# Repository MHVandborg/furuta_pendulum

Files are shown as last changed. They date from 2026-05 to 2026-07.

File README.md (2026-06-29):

# Furuta Pendulum

A Furuta (rotary inverted) pendulum system controlled by a neural network running on a custom PCB.

The system consists of a horizontal rotating arm driven by a BLDC motor, with a freely swinging pendulum attached at the end. The neural network controller learns to swing up and balance the pendulum using reinforcement learning trained in a physics simulation, then deployed directly onto the MCU.

## End Goal — Double Furuta Pendulum

The ultimate goal is a **double Furuta pendulum**: motorised arm → first free pendulum → second free pendulum, all balanced simultaneously in the inverted position by a single neural network. The current hardware (PCB rev1) targets the single pendulum first as a validated stepping stone. Double Furuta requires a PCB rev2 with a third encoder.

---

## Control Architecture

### Single Furuta (PCB rev1 — current)

```
[AS5600 arm]  [AS5600 pendulum 1]
      |               |
      +-------+-------+
              |
        [Neural Network]  MLP 2×64, trained with PPO
        inputs:  θ_arm, θ_p1, ω_arm, ω_p1
        output:  torque_command (−1…+1)
              |
        [SimpleFOC / DRV8313]
              |
        [GBM2804H-100T BLDC]
```

### Double Furuta (PCB rev2 — future)

```
[AS5600 arm]  [AS5600 pendulum 1]  [AS5600 pendulum 2]
      |               |                    |
      +-----------+---+--------------------+
                  |
            [Neural Network]  MLP 2×64 (extended inputs), trained with SAC
            inputs:  θ_arm, θ_p1, θ_p2, ω_arm, ω_p1, ω_p2
            output:  torque_command (−1…+1)
                  |
            [SimpleFOC / DRV8313]
                  |
            [GBM2804H-100T BLDC]
```

A single NN handles both swing-up and balancing via curriculum learning — it trains near vertical first, then faces progressively larger starting angles.

---

## Repository Structure

```
furuta_pendulum/
├── firmware/          # Bare-metal C (ARM GCC, CMake) → firmware/README.md
├── hardware/
│   ├── pcb/           # KiCad schematic + layout → hardware/pcb/COMPONENTS.md
│   └── mechanical/    # Fusion 360 3D design files
├── neural_network/    # RL training + Gymnasium env + exported weights → neural_network/README.md
├── bootloader/        # UF2 bootloader binary for ATSAMD51J20A
└── docs/              # Datasheets and reference documents
```

---

## Toolchain

| Area | Tools |
|---|---|
| Firmware | ARM GCC, CMake, VS Code, Atmel-ICE + Tag-Connect TC2030 (SWD), UF2 bootloader |
| ML / Training | Python, TensorFlow / Keras, Gymnasium, PPO → SAC |
| Inference on MCU | TensorFlow Lite Micro (TFLM) |
| Mechanical | Fusion 360, PLA (FDM) |
| PCB | KiCad |

---

## PCB Revision History

| Rev | Tag | Date | Notes |
|-----|-----|---|---|
| 1 | [`hw-rev1`](../../releases/tag/hw-rev1) | 2026-06-07 | First production run — JLCPCB. Single Furuta (2 encoders) |
| 2 | *(planned)* | TBD | Add AS5600 #3 + third I2C bus for double Furuta |

---

## Further Reading

| Document | Contents |
|---|---|
| [ROADMAP.md](ROADMAP.md) | Full phased development plan with checklists |
| [hardware/pcb/COMPONENTS.md](hardware/pcb/COMPONENTS.md) | Component choices, rationale, and PCB design decisions |
| [firmware/README.md](firmware/README.md) | Firmware architecture, build instructions, peripheral map |
| [neural_network/README.md](neural_network/README.md) | RL training approach, simulation, reward design, export pipeline |

---

## Contact

If you use or build on this project, I'd love to hear about it! Feel free to open an issue or reach out directly.

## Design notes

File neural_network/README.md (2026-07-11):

# Neural Network — Training & Deployment

This directory contains the reinforcement learning training pipeline for the Furuta pendulum
controller. Two separate networks are trained in simulation and deployed to the MCU:

| Network | Role | Inputs |
|---|---|---|
| **Balance** | Keeps the pendulum upright once near vertical | 4 floats |
| **Swing-up** | Pumps energy into the pendulum from the resting position | 5 floats |

The firmware switches from swing-up to balance when the pendulum is both geometrically
close to vertical **and** has sufficient energy to stay there (see Handoff Condition below).

---

## Quick Start (new machine)

```powershell
# 1. Clone the repo and enter this directory
cd neural_network

# 2. Create a virtual environment
python -m venv venv

# 3. Activate it
.\venv\Scripts\Activate.ps1          # Windows PowerShell
# source venv/bin/activate           # Linux / macOS

# 4. Install all dependencies
pip install -r requirements.txt

# 5. Train the balance controller (~30–60 min on CPU, faster on GPU)
python train.py --mode balance

# 6. Train the swing-up controller
python train.py --mode swingup
```

> **Note:** The `venv/` folder is git-ignored. Every machine needs its own copy.
> Trained model files (`.zip`, `.tflite`) are also git-ignored — transfer them
> manually between machines (USB, network share, etc.).

---

## Requirements

- Python 3.11+
- No GPU required — CPU training works fine, just takes longer
- ~4 GB RAM minimum during training (PyTorch + 8 parallel envs)

Tested on Python 3.11 on Windows. Dependencies are pinned in `requirements.txt`.

---

## Directory Structure

```
neural_network/
├── envs/
│   ├── __init__.py
│   ├── physics.py           # Lagrangian equations of motion + RK4 integrator
│   └── furuta_env.py        # Gymnasium environment (reward, reset, observations)
├── train.py                 # PPO training script (balance + swing-up)
├── models/                  # Saved model checkpoints — git-ignored
│   ├── balance_best/        # Best balance checkpoint (saved during training)
│   ├── balance_final.zip    # Final balance model
│   ├── swingup_best/        # Best swing-up checkpoint
│   └── swingup_final.zip    # Final swing-up model
├── exported/                # TFLite files + C arrays for firmware — git-ignored
├── logs/                    # TensorBoard training logs — git-ignored
├── requirements.txt         # Python dependencies
└── README.md
```

---

## Training

### Commands

```powershell
# Balance controller — starts near vertical, curriculum widens starting angle
python train.py --mode balance

# Swing-up controller — always starts near hanging position
python train.py --mode swingup

# All options
python train.py --help
```

### Key arguments

| Argument | Default | Description |
|---|---|---|
| `--mode` | `balance` | Which controller to train |
| `--timesteps` | `2,000,000` | Total environment steps |
| `--n-envs` | `8` | Parallel training environments (scale to your CPU core count) |
| `--no-save` | off | Skip saving — use for quick smoke tests |

### How long does it take?

On a modern CPU (8 cores), expect ~1,000–1,500 steps/second with 8 parallel envs.

| Steps | Wall time | What you see |
|---|---|---|
| 60,000 | ~1 min | Random policy, no learning visible yet |
| 500,000 | ~8 min | Policy starts committing, reward improves |
| 2,000,000 | ~30 min | Full training — balance should hold reliably |

On a GPU the training is significantly faster. No code changes needed —
PyTorch detects CUDA automatically.

### Monitoring with TensorBoard

```powershell
# In a separate terminal, from the neural_network directory
.\venv\Scripts\tensorboard --logdir logs
# Then open http://localhost:6006 in a browser
```

Key metrics to watch:
- `rollout/ep_rew_mean` — mean episode reward, should climb toward 0
- `train/explained_variance` — how well the critic understands the environment, should climb toward 1.0
- `train/entropy_loss` — policy randomness, should decrease as policy commits to learned behaviour

### Training order

Train **balance first** — it is easier (starts near vertical, clean reward signal) and
the curriculum is well-defined. Once balance works, train swing-up.

---

## Architecture

### Two controllers, same observation format

Both networks receive the same base observation:

```
[0]  sin(θ₁)            arm angle sine   — periodic, no ±π discontinuity
[1]  cos(θ₁)            arm angle cosine — periodic, no ±π discontinuity
[2]  (θ₂ − π) / π      pendulum error: 0 = upright, ±1 = hanging
[3]  ω₁ / ω₁_max       arm angular velocity, clipped to [-1, 1]
[4]  ω₂ / ω₂_max       pendulum angular velocity, clipped to [-1, 1]
```

The arm angle uses a (sin, cos) pair instead of a single normalised angle.
A raw `θ/π` representation has a discontinuity at the ±π wrap boundary —
the network sees a sudden jump from +1 to -1 for what is physically the
same continuous rotation.  (sin, cos) is smooth and periodic everywhere.

The swing-up network gets one extra input:

```
[5]  E_err / E_max      energy error: 0 = exactly enough to reach vertical
                        negative = needs more energy, positive = over-energised
```

Energy is a more informative input for swing-up than angle alone — it tells the
network exactly how much more pumping is needed, regardless of the current angle.

### Network

Both networks: MLP, 2 hidden layers × 64 neurons, tanh activation.

| | Balance | Swing-up |
|-|---|---|
| Inputs | 5 | 6 |
| Hidden layers | 2 × 64, tanh | 2 × 64, tanh |
| Output | 1 (normalised torque) | 1 (normalised torque) |

Small networks are intentional — they must run at 500 Hz on the SAMD51 M4F MCU.

### Reward functions

**Balance:**
```
r = cos(θ_err) − arm_coeff·w1_norm²·max(0,cos(θ_err)) − effort_coeff·u²
```
`cos(θ_err)` gives +1 at perfect balance, −1 hanging. The arm penalty is gated
so the agent can swing freely during recovery. The effort penalty (`effort_coeff=0.001`)
discourages high-frequency torque chattering on real hardware — at full torque the cost
is 0.001/step, which is small enough not to inhibit corrections.

**Swing-up:**
```
r = cos(θ₂ − π)                  range: [-1, +1]
```
+1 when upright, −1 when hanging. No penalties — the agent must spin freely.

### Curriculum learning (balance only)

The `difficulty` parameter (0–1) controls how far from vertical episodes start:

| `difficulty` | Starting range |
|---|---|
| 0.0 | ±5° (easy — almost already balanced) |
| 0.15 | ±30° |
| 0.50 | ±90° (horizontal) |
| 1.0 | ±180° (fully random) |

The `CurriculumCallback` in `train.py` automatically advances difficulty as
`ep_rew_mean` crosses the thresholds `-2.0 → -0.5 → -0.1`.

### Domain randomisation

On every `reset()`, all physical parameters are re-sampled within ±20% of their
nominal values. This forces the policy to generalise across manufacturing tolerances
and modelling errors, reducing the sim-to-real gap.

---

## Physics Simulation

Implemented directly in `envs/physics.py` — no external physics engine.

**Lagrangian equations of motion:**

```
Arm:       M₁₁(θ₂)·α₁ = τ − b₁·ω₁ − 2·m₂·(L₁ + Lp·sinθ₂)·Lp·cosθ₂·ω₁·ω₂
Pendulum:  Jp·α₂      = −b₂·ω₂ + m₂·(L₁ + Lp·sinθ₂)·Lp·cosθ₂·ω₁² − m₂·g·Lp·sinθ₂
                                   └── centrifugal (swing-up) ───────┘   └── gravity ─┘
```

Integrated with **RK4** at 1 ms (1 kHz). Two integration steps per control step
→ 500 Hz effective control rate, matching the firmware loop.

**Physical parameters** (update from Fusion 360 CAD after mechanical design):

| Symbol | Nominal | Description |
|---|---|---|
| L₁ | 0.15 m | Arm length: motor shaft → pendulum pivot |
| m₁ | 0.05 kg | Arm mass |
| L₂ | 0.20 m | Pendulum length: pivot → tip |
| m₂ | 0.03 kg | Pendulum mass |
| b₁ | 1.0×10⁻³ N·m·s/rad | Arm viscous friction |
| b₂ | 5.0×10⁻⁴ N·m·s/rad | Pendulum viscous friction |

> These are placeholders. Update `FurutaParams.nominal()` in `envs/physics.py`
> once real measurements are available from the CAD model or system identification.

---

## Handoff Condition

The firmware switches from swing-up to balance when **both** are true:

```
|θ₂ − π| < 20°          (geometrically near vertical)
E_pendulum > E_upright − 0.05 J   (has enough energy to stay there)
```

Using both conditions prevents handing off when the pendulum is geometrically
"near" vertical but already falling back with insufficient energy.

---

## Export to MCU

After training, convert the models to a format the MCU can run:

```powershell
# Step 1: Export both models to TFLite
python export_model.py
# Output: exported/balance_policy.tflite
#         exported/swingup_policy.tflite

# Step 2: Convert to C byte arrays for embedding in firmware
# (run from repo root, requires xxd — available in Git Bash on Windows)
xxd -i neural_network/exported/balance_policy.tflite > firmware/control/balance_model_data.cc
xxd -i neural_network/exported/swingup_policy.tflite > firmware/control/swingup_model_data.cc
```

The `.cc` files are compiled directly into the firmware image. Both models live
in flash and are interpreted by the TFLM library — no file system or OS needed.

---

## System Identification

For a tighter sim-to-real fit, measure real motor inertia and friction from hardware:

1. Flash a test firmware that commands known torque steps
2. Record angular acceleration α from the AS5600 encoder
3. Fit `τ = J·α + b·ω` (linear regression) → extract real J and b
4. Update `FurutaParams.nominal()` with measured values
5. Retrain with tighter domain randomisation (±10% instead of ±20%)

See the ROADMAP for the full procedure.

---

## Double Furuta (Future — rev2)

- Extend observation to 6 inputs: `[θ_arm, θ_p1, θ_p2, ω_arm, ω_p1, ω_p2]`
- Extend physics to the double-pendulum Lagrangian
- Switch algorithm from PPO to **SAC** (better sample efficiency for 6D control)
- Consider LSTM policy for the coupled dynamics (see ROADMAP rev2 notes)

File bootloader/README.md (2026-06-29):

# Bootloader

Adafruit UF2 bootloader for the ATSAMD51J20A on the Furuta Pendulum Controller PCB.

**File:** `bootloader-feather_m4-v4.0.0.bin`  
**Source:** https://github.com/adafruit/uf2-samdx1/releases/tag/v4.0.0

## Flash via Atmel-ICE (first time or recovery)

Requires: Atmel-ICE connected via SWD, OpenOCD installed.

```powershell
openocd -f interface/cmsis-dap.cfg -f target/atsame5x.cfg -c "program bootloader/bootloader-feather_m4-v4.0.0.bin verify reset exit 0x00000000"
```

Run this from the project root: `C:\Electronics\furuta_pendulum`

## Enter bootloader mode (USB)

Double-tap RESET quickly (<500ms between taps).  
Board appears as USB drive **FEATHERBOOT** — drag and drop a `.uf2` firmware file onto it.

## Normal firmware update (after bootloader is installed)

1. Double-tap RESET → FEATHERBOOT drive appears
2. Copy your `.uf2` file onto the drive
3. Board reboots automatically into new firmware

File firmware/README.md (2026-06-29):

# Firmware

Bare-metal C firmware for the ATSAMD51J20A. Implements sensor reading, motor control, and
real-time neural network inference using TensorFlow Lite Micro.

---

## Architecture

```
firmware/
├── hal/                   # Low-level peripheral drivers (direct register access)
│   ├── i2c.c/h            # SERCOM I2C (two independent buses)
│   ├── spi.c/h            # SERCOM SPI (LCD)
│   ├── pwm.c/h            # TCC0 3-phase centre-aligned PWM
│   ├── usb_cdc.c/h        # USB CDC — debug printf output
│   └── gpio.c/h           # GPIO init helpers
├── drivers/               # Device-level drivers (built on hal/)
│   ├── as5600.c/h         # AS5600 encoder: read raw angle, compute velocity
│   └── st7735s.c/h        # ST7735S LCD: init, draw text/values
├── control/               # Controller logic
│   ├── foc.c/h            # DRV8313 interface: torque command → PWM duty cycles
│   ├── nn_inference.c/h   # TFLM inference: state[4] → torque_out
│   └── nn_model_data.cc   # Generated: xxd of the .tflite model (flash-stored weights)
└── main.c                 # Entry point, system init, 500Hz control loop
```

---

## Control Loop (500Hz)

```
1. Read AS5600 arm encoder      (I2C0 — SERCOM0, PA00/PA01)
2. Read AS5600 pendulum encoder (I2C1 — SERCOM4, PB08/PB09)
3. Differentiate angles → angular velocities (+ low-pass filter)
4. Normalise state: [θ_arm, θ_p, ω_arm, ω_p]
5. nn_inference(state, &torque)
6. foc_set_torque(torque)        → TCC0 PWM → DRV8313
```

---

## Build

### Prerequisites

- ARM GCC (`arm-none-eabi-gcc`)
- CMake ≥ 3.20
- VS Code with the Cortex-Debug extension (optional but recommended)

### Compile

```bash
cmake -B build -DCMAKE_BUILD_TYPE=Release
cmake --build build
```

Output: `build/furuta_pendulum.elf` and `build/furuta_pendulum.uf2`

### Flash (first time — SWD via Atmel-ICE)

```bash
openocd -f interface/cmsis-dap.cfg -f target/atsame5x.cfg \
  -c "program build/furuta_pendulum.elf verify reset exit"
```

### Flash (subsequent updates — USB UF2)

1. Double-tap the RESET button quickly (< 500ms between taps)
2. A USB drive called **FEATHERBOOT** appears
3. Copy `build/furuta_pendulum.uf2` onto the drive
4. Board reboots automatically into new firmware

---

## Coding Rules (non-negotiable)

- **Pure C11** — no C++, no HAL, no ASF, no Arduino frameworks
- **No dynamic allocation** — no `malloc`, no `new`; all buffers are statically sized
- **Direct register access** via CMSIS headers only (`SERCOM0->I2CM.CTRLA.reg = ...`)
- `volatile` on all hardware register accesses
- Control loop target: **500–1000Hz**

---

## Peripheral Map

| Peripheral | Function | Pins |
|---|---|---|
| SERCOM0 (I2C) | AS5600 arm encoder | PA00 SDA, PA01 SCL |
| SERCOM3 (SPI) | ST7735S LCD | PA22 MOSI, PA23 SCK |
| SERCOM4 (I2C) | AS5600 pendulum encoder | PB08 SDA, PB09 SCL |
| TCC0 | 3-phase PWM (FOC) | PA08 WO0, PA09 WO1, PA10 WO2 |
| USB | CDC debug output | PA24 DM, PA25 DP |
| EIC | DRV_FAULT interrupt | PA12 |
| EIC | Button interrupt | PB01 |
| GPIO out | DRV_EN, DRV_SLEEP, DRV_RESET | PA11, PA13, PA14 |
| GPIO out | LED1, LED2 | PB02, PB03 |
| GPIO out | LCD_RST, LCD_CS, LCD_DC | PA19, PA20, PA21 |
| SWD | Debug / programming | PA30 SWDIO, PA31 SWDCLK |

---

## Neural Network Inference (TFLM)

The trained Keras model is converted to a `.tflite` file and then embedded as a C byte array
in flash. TensorFlow Lite Micro (TFLM) interprets the model at runtime — no dynamic
allocation, no operating system required.

**Generating `nn_model_data.cc` from a trained model:**

```bash
# On the training machine (Python)
python neural_network/export_model.py          # outputs furuta_policy.tflite

# Convert to C array
xxd -i furuta_policy.tflite > firmware/control/nn_model_data.cc
```

**Inference in firmware (`nn_inference.c`):**
- Static tensor arena (no heap)
- Input: `float state[4]` — normalised [θ_arm, θ_p, ω_arm, ω_p]
- Output: `float torque` — clamped to [−1.0, +1.0]
- Typical latency: < 100µs at 120MHz on the M4F

---

## Debug Output

All debug output goes over **USB CDC** (`printf` → USB serial, no UART).  
Connect with any serial terminal at any baud rate (USB CDC is baud-agnostic):

```bash
# Linux / macOS
screen /dev/ttyACM0

# Windows — use PuTTY or VS Code serial monitor
```

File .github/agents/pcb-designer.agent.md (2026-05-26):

---
description: "Use when designing, reviewing, or modifying the KiCad PCB schematic or layout. Handles component placement, net connections, DRC, footprint generation, and export for the Furuta pendulum custom PCB."
tools: [view, edit, create, grep, glob, powershell]
---

You are a PCB design specialist for the Furuta pendulum project. You work directly with KiCad schematic files (`.kicad_sch`) as text using file-reading tools.

## How to Read Schematics
KiCad `.kicad_sch` files are S-expression text files. Key patterns:
- Placed components: `(symbol (lib_id "...") ... (property "Reference" "R1") (property "Value" "10k") (property "Footprint" "...") ...)`
- Net labels: `(label "NET_NAME" ...)`
- Global power: `(global_label ...)` or `(symbol ... (lib_id "power:+3V3") ...)`
- No-connects: `(no_connect ...)`
- Wires: `(wire (pts (xy x1 y1) (xy x2 y2)) ...)`

Files over 50KB must be read with `view` using `view_range`, or searched with `grep`. The schematic at `hardware/pcb/furuta_pendulum.kicad_sch` is ~566KB — use targeted grep searches.

## Extraction Pattern
To extract all placed components with their ref/value/footprint, use PowerShell:
```powershell
$sch = Get-Content "hardware/pcb/furuta_pendulum.kicad_sch"
$i = 0; $capturing = $false; $depth = 0; $results = @()
foreach ($line in $sch) {
    $i++
    if ($i -lt 13108) { continue }  # lib_symbols ends around line 13107
    if ($line -eq "`t(symbol") { $capturing = $true; $depth = 1; $ref=""; $val=""; $fp=""; continue }
    if ($capturing) {
        if ($line -match 'lib_id "([^"]+)"') { $libid = $Matches[1] }
        if ($line -match 'property "Reference" "([^"]+)"') { $ref = $Matches[1] }
        if ($line -match 'property "Value" "([^"]+)"') { $val = $Matches[1] }
        if ($line -match 'property "Footprint" "([^"]+)"') { $fp = $Matches[1] }
        $depth += ([regex]::Matches($line,'\(')).Count - ([regex]::Matches($line,'\)')).Count
        if ($depth -le 0) { $capturing = $false; if ($ref -notmatch '^#') { $results += "$ref`t$val`t$fp" } }
    }
}
$results | Sort-Object
```

## Your Responsibilities
- Review schematic for correctness against the KiCad guidelines
- Place and connect components in the schematic
- Identify missing footprints, wrong net names, ERC issues
- Assist with PCB layout and routing
- Export manufacturing files (Gerbers, BOM, pick-and-place)

## Key Components
- MCU: ATSAMD51J20A-A (TQFP-64, `Package_QFP:TQFP-64_10x10mm_P0.5mm`)
- Motor driver: DRV8313 (SimpleFOC Mini — external board, connect via header)
- Encoders: 2x AS5600 (external modules on JST-SH 4-pin 1mm connectors)
- Display connector: ST7735S (7-pin header)
- USB-C with ESD protection (USBLC6-2SC6)

## Constraints
- Always follow the KiCad guidelines in `.github/instructions/kicad.instructions.md` — read this file first
- Do NOT modify firmware files
- Do NOT modify neural_network files
- Verify footprints exist before placing components

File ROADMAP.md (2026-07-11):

# Furuta Pendulum — Roadmap

This document tracks the development phases from an empty repo to a working double Furuta
pendulum balanced by a neural network.

---

## Phase 0 — Toolchain & Firmware Scaffold

Get a compilable project on the MCU and confirm the flash pipeline works.

- [ ] ARM GCC + CMake build system configured, VS Code tasks defined
- [ ] Folder structure: `firmware/hal/`, `firmware/drivers/`, `firmware/control/`, `firmware/main.c`
- [ ] Flash UF2 bootloader via Atmel-ICE + OpenOCD (one-time, SWD)
- [ ] Blink onboard LED (smoke-test that code runs on hardware)
- [ ] USB CDC debug output — `printf` over USB, no UART needed

---

## Phase 1 — Hardware Validation *(no NN yet)*

Validate every sensor and actuator in isolation before integrating the controller.

- [ ] I2C0 driver → read AS5600 arm encoder angle (SERCOM0, PA00/PA01)
- [ ] I2C1 driver → read AS5600 pendulum encoder angle (SERCOM4, PB08/PB09)
- [ ] Pendulum encoder zero calibration on boot: let pendulum hang still, record raw
  count as `zero_offset`, compute `θ₂ = (raw − zero_offset) / 4096 × 2π` from
  then on. The network convention is θ₂=0 at hanging, θ₂=π at upright — if this
  offset is wrong the controller will drive the motor the wrong way.
- [ ] TCC0 3-phase PWM + DRV8313 startup sequence (EN, SLEEP, RESET, FAULT)
- [ ] Command a known torque and verify motor moves
- [ ] Log encoder angles + motor response continuously over USB CDC
- [ ] Confirm both sensors read correct angles through a full revolution

---

## Phase 2 — Mechanical Design

Design and print the physical structure. Physical dimensions extracted from CAD are used
directly as simulation parameters in Phase 3.

- [ ] Fusion 360: horizontal rotating arm (PLA)
- [ ] Fusion 360: pendulum rod and pivot bearing mount (PLA or metal rod for consistent mass distribution)
- [ ] 3D print and assemble on motor shaft
- [ ] Measure / extract from CAD:
  - Arm length L₁ and mass m₁ (moment of inertia about pivot)
  - Pendulum length L₂ and mass m₂ (moment of inertia about pivot)
- [ ] These values are the nominal parameters for the physics simulation

---

## Phase 3 — Physics Simulation + RL Environment

Build the Gymnasium environment the RL agent will train in.

- [ ] Set up Python environment (TensorFlow, Gymnasium, numpy, scipy)
- [ ] Implement Furuta pendulum equations of motion (Lagrangian formulation)
  - States: θ_arm, θ_pendulum, ω_arm, ω_pendulum
  - Input: torque τ
  - Output: θ̈_arm, θ̈_pendulum → integrate with fixed timestep
- [ ] Wrap in a Gymnasium `Env` subclass:
  - `observation_space`: Box(4,) — [θ_arm, θ_p, ω_arm, ω_p] normalised
  - `action_space`: Box(1,) — torque in [−1, +1]
  - `reset()`: randomise starting state (curriculum-controlled)
  - `step()`: advance physics, compute reward, check termination
- [ ] Dense reward: `r = -(θ_p² + 0.01·ω_arm²)` per timestep
  - Heavily penalises deviation from vertical
  - Small penalty on arm velocity to discourage wild spinning
- [ ] Domain randomisation: sample L₁, L₂, m₁, m₂, friction within ±20% of nominal on each `reset()`
- [ ] Curriculum learning: start `reset()` near vertical (±5°), gradually widen to full range as training improves
- [ ] Smoke-test: verify a hand-coded near-optimal action produces positive reward signal

---

## Phase 4 — RL Training (single Furuta, PPO)

Train the neural network policy entirely in simulation.

- [ ] Train a PPO agent on the Gymnasium environment
  - Policy network: MLP, 2 hidden layers × 64 neurons, tanh activation
  - Inputs: [θ_arm, θ_p, ω_arm, ω_p] (4 values)
  - Output: torque command (1 continuous value)
- [ ] Validate policy in simulation — pendulum holds balance for > 30 seconds from arbitrary start
- [ ] *(Optional but recommended)* Motor system identification:
  - Command torque steps via firmware, record α from encoder
  - Fit `τ = J·α + b·ω` to get real J, b values
  - Update nominal sim parameters, retrain with tighter domain randomisation bounds
- [ ] Export trained model:
  1. Save Keras model: `model.save('furuta_policy.h5')`
  2. Convert to TFLite: `TFLiteConverter.from_keras_model(model)` → `furuta_policy.tflite`
  3. Convert to C array: `xxd -i furuta_policy.tflite > firmware/control/nn_model_data.cc`

---

## Phase 5 — TFLM Firmware Integration

Bring the trained policy onto the MCU and close the real hardware loop.

- [ ] Add TensorFlow Lite Micro source tree to CMake build
- [ ] `firmware/control/nn_inference.c`:
  - Load model from C byte array in flash
  - Allocate tensor arena (static, no malloc)
  - Expose `nn_inference(float state[4], float *torque_out)`
- [ ] Full 500Hz control loop in `main.c`:
  1. Read both AS5600 encoders
  2. Compute angular velocities (differentiate + low-pass filter)
  3. Normalise state vector
  4. Run NN inference → torque command
  5. Send torque command to DRV8313 via SimpleFOC
- [ ] Test on real hardware
- [ ] Identify and close sim-to-real gaps:
  - Log real state trajectories over USB CDC
  - Compare to sim predictions
  - Update sim parameters if needed, retrain if gap is large

---

## Phase 6 — Double Furuta *(requires PCB rev2)*

Extend the hardware, simulation, and controller to the double pendulum configuration.

### Hardware
- [ ] PCB rev2 design: switch all 3 encoders to AS5048A (SPI) — see Rev2 notes below
- [ ] Order and assemble PCB rev2
- [ ] Design pendulum 2 arm and pivot mount in Fusion 360
- [ ] Extract L₃, m₃ from CAD

### Simulation
- [ ] Extend equations of motion to double-pendulum Lagrangian (6 state variables)
  - Additional states: θ_p2, ω_p2
- [ ] Extend `observation_space` to Box(6,)
- [ ] Retune reward and curriculum for the harder problem

### Training
- [ ] Switch from PPO to SAC (better sample efficiency for higher-dimensional continuous control)
- [ ] Extend policy network inputs from 4 → 6
- [ ] Train, validate, export as before

### Firmware
- [ ] Replace I2C encoder drivers with SPI AS5048A driver (shared bus, 3 CS pins)
- [ ] Extend state vector from 4 → 6 inputs
- [ ] Deploy new model, test on real hardware

---

## Rev2 PCB Improvement Notes

Ideas identified during rev1 development. Implement together with the Phase 6 hardware redesign.

### Encoder upgrade: AS5600 → AS5048A (SPI)

- **Why:** AS5048A is 14-bit (0.022°) vs AS5600 12-bit (0.088°). 4× better angle resolution
  gives 4× better velocity estimates near the balance point, which tightens balance quality
  for both the single and double pendulum.
- **Double pendulum motivation:** 6-state control compounds velocity noise across two
  pendulums. Noisy ω_p1 and ω_p2 simultaneously makes the harder balancing problem
  significantly worse. The upgrade is clearly worthwhile at rev2.
- **Bus simplification:** All three AS5048A encoders share one SPI bus — just different CS
  pins (e.g. PA15, PA16, PA17). Eliminates the two-I2C-bus workaround needed because both
  AS5600s share the hardwired address 0x36.
- **Speed:** SPI at 10 MHz → ~3 μs/read vs ~90 μs/read over I2C. Parallel CS transactions
  possible; all three reads complete in under 10 μs total.

### I2C Fast Mode+ on rev1 (no hardware change needed)

- AS5600 supports up to 1 MHz (Fast Mode+). Rev1 firmware uses 400 kHz.
- Changing the SERCOM baud register halves read latency to ~36 μs/encoder at no cost.
- Worth doing in firmware before committing to the encoder swap.

### Control loop frequency

- 500 Hz is already ~15× the pendulum's natural frequency (~1.6 Hz) — well beyond what
  the single pendulum dynamics require.
- Higher frequency (1 kHz) improves velocity estimate quality (finer finite-difference
  resolution) but provides no additional control-theoretic benefit for the single pendulum.
- For the double pendulum, the second pendulum's higher-frequency modes may justify 1 kHz.
  Re-evaluate after rev1 balance is working.

### Velocity estimation: EMA filter in firmware

- Velocities are computed by finite-differencing successive encoder readings, which produces
  a noisy staircase signal near the balance point (smallest detectable ω ≈ 44°/s with AS5600).
- An Exponential Moving Average (EMA) filter in firmware handles this at zero cost:
    `ω_filtered = α·ω_raw + (1−α)·ω_filtered_prev`
- This is one multiply + one add per loop iteration. No network change needed.
- α ≈ 0.3–0.5 is a good starting range; tune on real hardware by watching the USB CDC log.
- Do this before considering any network architecture changes for noise.

### Motor dynamics modelling

- Currently the sim assumes torque is delivered instantaneously. Real motors have inductance
  lag and back-EMF that cause the delivered torque to lag the commanded torque.
- **System identification procedure (after firmware can command torques):**
  1. Command a series of known torque steps via firmware
  2. Record angular acceleration α from the encoder at each step
  3. Fit `τ = J·α + b·ω` (linear regression) to extract real J and b values
  4. Add a first-order lag model: `τ_actual(s) = τ_cmd(s) / (1 + T_motor·s)`
  5. Update `FurutaParams` nominal values and retrain with tighter domain randomisation (±10%)
- This is a one-day task once hardware is working and is the single biggest lever for
  closing the sim-to-real gap.

### Swing-up / balance handoff condition

- Current firmware plan uses a pure angle threshold (|θ₂ − π| < 20°) to switch networks.
- Better condition uses both angle AND energy:
    switch when |θ₂ − π| < 20°  AND  E_pendulum > E_upright − 0.05 J
- The energy condition prevents handing off when the pendulum is geometrically "near"
  vertical but already falling back down with insufficient energy to stay there.
- E_upright = mp·g·Lp — computed from FurutaParams; update after mechanical design.

### Neural network architecture improvements (post rev1)

- **Frame stacking for balance (fallback):** If balance is noisy after EMA tuning, feed
  the last 2–3 observations as input [s_t, s_{t-1}, s_{t-2}] = 12 floats. The network
  learns its own implicit filter. A circular buffer in firmware RAM handles this trivially.
  Try EMA first — this is only needed if the firmware filter is insufficient.
- **Previous action as input:** Feeding the last torque command helps the network account
  for motor lag not captured in the physics model. Low cost: 1 extra input to both networks.
- **Recurrent networks (LSTM/GRU) for rev2 / double pendulum:** LSTM maintains hidden state
  between loop iterations, learning arbitrary temporal patterns. Harder to train than MLP
  but genuinely useful for the 6-state double pendulum where coupled dynamics are harder
  to observe cleanly. CMSIS-NN supports it. Revisit when extending to double pendulum.

---

## Hardware at a Glance

| Item | PCB Rev | Status |
|---|---|---|
| 2× AS5600 encoder | rev1 | On PCB |
| GBM2804H-100T motor | rev1 | — |
| SimpleFOC Mini (DRV8313) | rev1 | — |
| ST7735S 1.8" LCD | rev1 | — |
| Atmel-ICE + Tag-Connect | — | — |
| UF2 bootloader binary | — | ✅ In repo |
| 3× AS5048A encoder (SPI) | rev2 | Planned |

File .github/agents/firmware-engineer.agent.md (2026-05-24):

---
description: "Use when writing, reviewing, or debugging bare-metal firmware for the ATSAMD51J20A. Handles peripheral initialization, control loop, CMSIS-NN inference, and USB CDC debug output."
tools: [read, edit, search, execute]
---

You are a bare-metal embedded firmware engineer for the Furuta pendulum project. You write clean, direct register-level C code for the ATSAMD51J20A with no HAL or framework dependencies.

## Your Responsibilities
- Write and review firmware in `firmware/`
- Initialize peripherals via direct register access (CMSIS headers)
- Implement the real-time control loop (500–1000Hz)
- Integrate CMSIS-NN for neural network inference
- Debug via USB CDC

## Constraints
- NEVER use HAL, ASF, Arduino, or any vendor framework
- NEVER use dynamic memory allocation (`malloc`, `new`)
- Always follow conventions in `.github/instructions/firmware.instructions.md`
- Do NOT modify PCB or KiCad files
- Do NOT modify neural_network training scripts

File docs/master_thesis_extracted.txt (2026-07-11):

--- PAGE 1 ---
 
Department of Automatic Control 
 
Robust Reinforcement Learning Control 
of a Furuta Pendulum 
Philip Olhager 

--- PAGE 2 ---

MSc Thesis 
TFRT-6150 
ISSN 0280-5316 
Department of Automatic Control 
Lund University 
Box 118 
SE-221 00 LUND 
Sweden 
© 2021 by Philip Olhager. All rights reserved. 
Printed in Sweden by Tryckeriet i E-huset 
Lund 2021 

--- PAGE 3 ---
Abstract
The use of Reinforcement Learning (RL) to design controllers for safety criti-
cal systems is an important research area. On the one hand, RL can function
in and adapt to complex and changing environments without requiring a
model of the system. On the other hand, in such systems robustness is of
high importance, as well as ways to guarantee and certify a level of robust-
ness. This project investigates state-of-the-art methods for training for and
evaluating robustness in a neural network, when applied to RL control of
a real-world system. The use of Projected Gradient Descent (PGD) as an
adversary for robust Deep RL, as well as the Lipschitz constant as a measure
of a neural network controller’s robustness, are evaluated.
The study is conducted by training an agent to perform swing-up and
balancing of a Furuta pendulum, and further training it with PGD of varying
magnitudes as an adversary. The agents are evaluated by their robustness
towards normally-distributed measurement noise as well as their estimated
Lipschitz constant.
The results show that while training with PGD does result in better ro-
bustness for a classiﬁer on the MNIST dataset, applying the technique to the
Furuta pendulum in a Deep Reinforcement Learning setting is not so simple.
One of 30 agents managed to outperform the baseline agent, indicating that
while the technique may have some promise, further ﬁne-tuning of the train-
ing process is necessary. Further, the Lipschitz constant did not correlate
with robustness performance, indicating that it may not be an ideal measure
of a neural network’s robustness.
3

--- PAGE 4 ---

--- PAGE 5 ---
Acknowledgements
I would like to thank Richard Pates and Johan Grönqvist for supervising the
project, and suggesting the topic. I would also like to thank Anders Nilsson
and Anders Blomdell for their help in interfacing with a physical pendulum,
experiments with which could unfortunately not be incorporated in the ﬁnal
report due to time constraints.
5

--- PAGE 6 ---

--- PAGE 7 ---
Contents
Acronyms 9
1. Introduction 10
1.1 Background . . . . . . . . . . . . . . . . . . . . . . . . . . . 10
1.2 Problem Description . . . . . . . . . . . . . . . . . . . . . . 12
2. Theory 13
2.1 Furuta pendulum . . . . . . . . . . . . . . . . . . . . . . . . 13
2.2 Classical controller . . . . . . . . . . . . . . . . . . . . . . . 15
2.3 Reinforcement Learning controller . . . . . . . . . . . . . . . 17
2.4 Lipschitz constants . . . . . . . . . . . . . . . . . . . . . . . 23
3. Method 27
3.1 MNIST . . . . . . . . . . . . . . . . . . . . . . . . . . . . . . 27
3.2 Furuta pendulum . . . . . . . . . . . . . . . . . . . . . . . . 28
4. Results 33
4.1 MNIST . . . . . . . . . . . . . . . . . . . . . . . . . . . . . . 33
4.2 Furuta pendulum . . . . . . . . . . . . . . . . . . . . . . . . 36
5. Discussion and Conclusion 39
5.1 MNIST . . . . . . . . . . . . . . . . . . . . . . . . . . . . . . 39
5.2 Furuta pendulum . . . . . . . . . . . . . . . . . . . . . . . . 40
5.3 Conclusions . . . . . . . . . . . . . . . . . . . . . . . . . . . 42
Bibliography 43
A. MOSEK formulation of Lipschitz SDP 45
B. T able of F uruta results 47
C. F uruta pendulum plots 49
7

--- PAGE 8 ---

--- PAGE 9 ---
Acronyms
CPU Central Processing Unit
DDPG Deep Deterministic Gradient Descent
DQN Deep Q-Network
FGSM Fast Gradient Sign Method
GPU Graphics Processing Unit
LQR Linear Quadratic Regulator
MDP Markov Decision Process
MSE Mean-Square Error
NaN Not a Number
NN (Artiﬁcial) Neural Network
PGD Projected Gradient Descent
RAM Random Access Memory
ReLU Rectiﬁed Linear Unit
RL Reinforcement Learning
SARS State, Action, Reward, next State
SAR TSState, Action, Reward, Terminal, next State
SDP Semi-Deﬁnite Program
VRAM Video Random Access Memory
9

--- PAGE 10 ---
1
Introduction
Figure 1.1: A Furuta pendulum.
1.1 Background
Machine Learning techniques, in particular Reinforcement Learning (RL),
have been gaining interest within control applications due to their ability to
function in complex and changing environments. Deep Reinforcement Learn-
ing is a subset of these techniques which uses neural networks instead of
the more traditional lookup tables. Lookup tables store one action for each
possible combination of observations, which requires a discrete observation
space. Neural networks, on the other hand, allow the methods to handle con-
tinuous observations and in some cases continuous actions, which is often the
10

--- PAGE 11 ---
1.1 Background
case in control applications. Model-free deep RL methods, like DQN (Deep
Q-Network) [Mnih et al., 2013] and DDPG (Deep Deterministic Policy Gra-
dient) [Lillicrap et al., 2015] are of particular interest since they allow for
implementation on systems that are diﬃcult to model or entirely unknown.
Due to these models’ adaptability, safety-critical systems is an interesting
application. In order to function in such applications, the controller must
have a certain level of robustness. In particular, the controller should have a
certiﬁed and guaranteed level of robustness.
There have been recent eﬀorts within the control community to analyze,
improve and guarantee levels of robustness for neural network controllers.
An important example is [Fazlyab et al., 2019] which presents a method to
estimate the Lipschitz constant for a deep neural network. The Lipschitz
constant is typically used as a robustness certiﬁcation metric of sorts within
control theory, and [Fazlyab et al., 2019] is a step towards applying this
concept to neural networks. One popular method for improving robustness
during training of neural networks is the concept of adversarial attacks, pro-
viding the network with some form of worst-case perturbations on the inputs
during training. [Huang et al., 2017] applied the Fast Gradient Sign Descent
(FGSM) method [Goodfellow et al., 2015] to a Deep RL setting. FGSM is a
single gradient step with a ﬁxed step size, making it a basic ﬁrst-order ad-
versary. [Pattanaik et al., 2017] added a variable step-size by sampling noise
from a beta distribution. This introduces some stochasticity in the training
process, which gave better results. [Oikarinen et al., 2020] augmented the loss
function itself to account for worst-case perturbations, moving the robust-
ness training from environment interaction into the network updates. [Madry
et al., 2019] proposed the projected gradient descent as the "ultimate" ﬁrst-
order adversary to a neural network and applied it to image classiﬁcation
on the MNIST [LeCun and Cortes, 2010] and CIFAR-10 [Krizhevsky, 2009]
datasets. This method proved eﬀective at improving the robustness of the
classiﬁers. It has yet to be tested for Reinforcement Learning schemes, but
due to its eﬀectiveness for supervised learning and its theoretical strength
as a ﬁrst-order adversary, it was chosen as the method to be used in this
project.
The Furuta pendulum [Furuta et al., 1991], see Figure 1.1, is an exten-
sion of the swing-up cartpole experiment, which is a very commonly used
benchmark within control literature. It is highly non-linear and oﬀers a chal-
lenging environment for the controller to operate in. At the same time, there
are methods to extract a highly functional controller using classical theoret-
ical methods, which provides a good comparison for the rl controllers.
11

--- PAGE 12 ---
Chapter 1. Introduction
1.2 Problem Description
The primary goal of this project is to take the theoretical results of [Fazlyab
et al., 2019] and [Madry et al., 2019], which demonstrated that PGD training
reduces the Lipschitz constant and improves robustness of neural networks,
and investigate how this transfers to an RL controller of a physical system.
This will be the ﬁrst attempt at using PGD for adversarial training on Re-
inforcement Learning. In doing this, we will investigate its eﬀectiveness at
improving the robustness and/or reducing the Lipschitz constant of the con-
troller, as well as the relation between the controller’s Lipschitz constant and
its robustness for a practical system. To do this, we will ﬁrst demonstrate the
method on the simpler case of image classiﬁcation on the MNIST dataset. We
will then train a DDPG agent on a simulated Furuta pendulum and augment
it with PGD training with varying perturbation bounds. These augmented
agents will be analyzed with respect to their robustness to measurement noise
in simulation and on a physical process as well as their estimated Lipschitz
constants, and compared to the classical controller and the baseline agent.
The questions we seek to answer are these:
• Does PGD training increase robustness to measurement noise in a
DDPG controller of a Furuta pendulum?
• Does PGD training reduce the Lipschitz constant of a DDPG controller
of a Furuta pendulum?
• DoestheLipschitzconstantofaDDPGcontrollerofaFurutapendulum
correlate with its robustness to measurement noise?
12

--- PAGE 13 ---
2
Theory
In this section, relevant theory concerning the Furuta pendulum, the classical
controller, the RL controller and Lipschitz constants, is presented.
2.1 Furuta pendulum
Figure 2.1: The Furuta pendulum. [Gäfvert, 1998]
The Furuta pendulum [Furuta et al., 1991] consists of a pendulum attached
to the end of a rotating arm, see Figure 2.1. The pendulum has uniformly
distributed massmp and lengthlp, the arm has uniformly distributed mass
ma and lengthla, and the center pillar has moment of inertiaJ. At the end
of the pendulum is a spherical massM. The pendulum angleθ is deﬁned
such thatθ = 0 corresponds to the upright position. The derivation for the
equations of motion is given in [Gäfvert, 1998].
13

--- PAGE 14 ---
Chapter 2. Theory
Deﬁning



α =J +
(
M + 1
3ma +mp
)
l2
a,
β =
(
M + 1
3mp
)
l2
p,
γ =
(
M + 1
2mp
)
lalp,
δ =
(
M + 1
2mp
)
glp,
(2.1)
the equations of motion can be written as
{
v = (α +β sin2θ)¨φ +γ cosθ¨θ + 2β cosθ sinθ ˙φ ˙θ−γ sinθ ˙θ2,
0 =γ cosθ ¨φ +β¨θ−β cosθ sinθ ˙φ2−δ sinθ, (2.2)
where v contains the (possibly rescaled) torques and forces applied to the
arm joint. Rewriting this to the standard form of˙ x= f(x) yields
d
dtθ = ˙θ,
d
dt
˙θ = 1
αβ−γ + (β2 +γ2) sin2θ
(
β(α +β sin2θ) cosθ sinθ ˙φ2
+ 2βγ(1− sin2θ) sinθ ˙φ ˙θ−γ2 cosθ sinθ ˙θ2 +δ(α +β sin2(θ)) sinθ−γ cosθv
)
,
d
dtφ = ˙φ,
d
dt
˙φ = 1
αβ−γ + (β2 +γ2) sin2θ
(
βγ(sin2θ− 1) sinθ ˙φ2
− 2β2 cosθ sinθ ˙φ ˙θ +βγ sinθ ˙θ−γδ cosθ sinθ +βv
)
.
(2.3)
This is the state-space description used in the simulation of the pendu-
lum. Linearizing this system at the equilibrium pointx0 = [θ0, ˙θ0,φ, ˙φ0]⊤ =
[0, 0, 0, 0]⊤ (i.e. upright stationary pendulum) yields the matrices
A =


0 1 0 0
αδ
αβ−γ2 0 0 0
0 0 0 1
− δγ
αβ−γ2 0 0 0

, B =


0
− γ
αβ−γ2
0
β
αβ−γ2

. (2.4)
The eigenvalues of thisA matrix are
{
0, 0,±
√
αδ
αβ−γ2
}
. (2.5)
14

--- PAGE 15 ---
2.2 Classical controller
One can verify that in the limit caseJ,ma→∞ and mp→ 0 the open-loop
poles for a simple pendulum are restored:
√
αδ
αβ−γ2→
√g
lp
. (2.6)
There exists signiﬁcant friction in theφ-joint. This friction is modelled in the
following way:
uF =



τC sgn ˙φ if ˙φ̸= 0,
u if ˙φ = 0 and|u|<τ S,
τS sgnu0 otherwise,
(2.7)
with v = u−uF, u being the nominal control signal, andτC and τS being
coeﬃcients for Coulomb friction and stiction respectively.
2.2 Classical controller
Designing a classical controller as a baseline for the swing-up problem can be
broken down into two steps: designing a balancing controller once the pen-
dulum is upright and designing a controller to make the pendulum swing up.
Designing a balancing controller can be done using various linear methods,
as the pendulum can be accurately linearized for small angle deviations. The
method of choice here is the Linear Quadratic Regulator (LQR). Designing
a swing-up controller is slightly more involved, as the system cannot be lin-
earized due to large angle deviations. The method used here is commonly
referred to as Lyapunov based design or energy shaping control.
LQR
Given a discrete-time LTI (Linear, Time-Invariant) system
xk+1 = Φxk + Γuk, (2.8)
the LQR method deﬁnes a quadratic cost function
J(x, u) =
T∑
k=0
(x⊤
k Qxk + u⊤
k Ruk + 2x⊤
k Nuk), (2.9)
where Q, R and N are chosen weight matrices, and formulates ﬁnding the
control law as an optimization problem:
min
u
J(x, u)
s.t. xk+1 = Φxk + Γuk, k= 0, 1,...,T.
(2.10)
15

--- PAGE 16 ---
Chapter 2. Theory
The solution to this problem is given byuk =−Kkxk with K given recur-
sively by the (discrete-time) Riccati equation:
{
Kk = (Γ⊤Sk+1Γ + R)−1(Φ⊤Sk+1Φ + N)⊤,
Sk = Φ⊤Sk+1Φ⊤ + Q− (Φ⊤Sk+1Γ + N)(Γ⊤Sk+1Γ + R)−1(Φ⊤Sk+1Γ + N)⊤.
(2.11)
As the time horizon approaches inﬁnity,Sk and Kk approach the stationary
S and K, and are given by the (discrete-time) algebraic Riccati equation:
{
K = (Γ⊤SΓ + R)−1(Φ⊤SΦ + N)⊤,
S = Φ⊤SΦ⊤ + Q− (Φ⊤SΓ + N)(Γ⊤SΓ + R)−1(Φ⊤SΓ + N)⊤.
(2.12)
To design a controller this way, one simply chooses the matricesQ, R and
N, and solves the Riccati equation using some numerical method. The result
is an optimal linear state-feedback controllerK, with the control signal given
by u =−Kx.
Lyapunov based design
To design a controller using Lyapunov based design, ﬁrst consider the Lya-
punov stability theorem:
Theorem 2.1. Given a system ˙x = f(x) with an equilibrium pointx∗ and
a functionV (x) deﬁned onΩ, if
i) V (x) = 0 for x = x∗,
ii) V (x)> 0 for x̸= x∗,
iii) ˙V (x) =∇V (x)⊤f(x)≤ 0 for all x∈ Ω,
then x∗ is stable. If instead of (iii) we have
iv) ˙V (x)< 0 for all x∈ Ω : x̸= x∗,
then x∗ is locally asymptotically stable. If instead of (iii) and (iv) we have
v) ˙V (x)< 0 for all x∈ Ω : x̸= x∗, Ω = Rn and V (x)→∞ as∥x∥2→∞ ,
then x∗ is globally asymptotically stable.
Applying this theorem is typically done by choosing a candidate Lyapunov
function and testing which parts of the theorem the function fulﬁl. If a func-
tion fulﬁls requirementsi)andii), and its time derivative contains the control
signalu, one can design thisu to achieve ˙V <0,x̸=x∗, guaranteeing asymp-
totic convergence to the desired equilibrium point. To do this for the Furuta
16

--- PAGE 17 ---
2.3 Reinforcement Learning controller
pendulum, approximate the model by a planar pendulum, simplifying the
equations of motion to
¨θ = mpglp
Jp
sinθ−umplp
Jp
cosθ. (2.13)
Deﬁningω0 =
√
mpglp
Jp
simpliﬁes this further to
¨θ =ω2
0 sinθ−uω2
0
g cosθ. (2.14)
The total energy (kinetic energy + potential energy) of the simpliﬁed pen-
dulum is
E =mpglp(cosθ− 1) +Jp
2
˙θ2 = cosθ− 1 + 1
2ω2
0
˙θ2. (2.15)
Taking our candidate Lyapunov function to beV (x) = E(x)2 with x =
[θ, ˙θ]⊤∈ Ω = [(−π,π ], (−∞,∞)], x∗ = [0, 0]⊤ fulﬁls conditions(i) and (ii)
of the Lyapunov stability theorem. Taking the time derivative ofV gives
˙V (x) =∇V (x)⊤f(x)
= 2
(
cosθ− 1 + 1
2ω2
0
˙θ2
)[
− sinθ
˙θ
ω2
0
][ ˙θ
ω2
0
(
sinθ− u
g cosθ
)
]
= − 2
gu ˙θ cosθ
(
cosθ− 1 +
˙θ2
2ω2
0
)
. (2.16)
We now wish to chooseu such that the above quantity is nonpositive for all
θ and ˙θ. There are many ways to do this, but in this project the expression
u =K
˙θ cosθ
(
cosθ− 1 +
˙θ2
2ω2
0
)
b +
⏐⏐⏐ ˙θ cosθ
(
cosθ− 1 +
˙θ2
2ω2
0
)⏐⏐⏐
, (2.17)
where K,b> 0 are tunable parameters, was used.
2.3 Reinforcement Learning controller
Reinforcement Learning
A Reinforcement Learning setup consists of an agent and an environment.
The agent takes actions based on observations provided by the environment,
and the environment returns a reward based on a predetermined reward
17

--- PAGE 18 ---
Chapter 2. Theory
function, as well as updated observations. The agent aims to take actions
that maximize the rewards. An environment is deﬁned as a Markov Decision
Process (MDP), consisting of the tuple (S,A,P,R,γ ) whereS is the set of
possible states,A is the set of possible actions,P :S×A×S→ R are the
state transition probabilities, R :S×A→ R is the reward function and
γ∈ [0, 1] is the discount factor. An RL algorithm aims to learn a (possibly
stochastic) policyπ :S×A→ R which describes the probabilities of taking
each possible action given a state. This policy then governs the actions taken
by the agent. The policy is learned by attempting to maximize the long-term
discounted rewardGt =∑∞
k=0γkrt+k+1 wheret is the current time step and
ri is the reward received at timestepi. This is typically done by deﬁning the
action-value functionqπ :S×A→ R which gives the expected value ofGt
given the current stateSt, and actionAt, and using the Bellman equation to
compute this function recursively
qπ(s,a ) = Eπ[rt +γqπ(St+1,At+1)|St =s,At =a]. (2.18)
In the most basic form, with discrete observation and action spaces,q can
be deﬁned as a lookup table. Constructing this function requires explicit
knowledge about the transition probabilities of the environment, which is
not always available. A model-free version of this is called Q-learning, which
aims to learn a functionQ approximatingq by interacting with the environ-
ment and observing rewards. During interaction with the environment, state
transitions are recorded in the form of the tuple(si,ai,ri,si+1), wheresi is
the observed state,ai is the action taken by the actor andri is the reward
obtained at timei. This format of recording transitions is called SARS.Q
then uses the following update formula, based on the Bellman equation:
Q(k+1)(si,ai) =Q(k)(si,ai) +α
(
ri +γmax
a
{Q(k)(si+1,a )}− Q(k)(si,ai)
)
,
(2.19)
where α is a learning rate.
Artiﬁcial Neural Networks
An artiﬁcial neural network (ANN or NN) is an attempt to mimic the inner
workings of the human brain. It consists of a number of "neurons" in diﬀerent
layers connected by weighted "synapses". See Figure 2.2 for an illustration.
Each neuron receives the weighted outputs from the previous layers as inputs
and applies an "activation function" to the sum of the inputs.
18

--- PAGE 19 ---
2.3 Reinforcement Learning controller
Figure 2.2: A conceptual illustration of a neural network.
Given inputs x, weight matricesWk and activation functionsϕk(·), for an
NNwith nhiddenlayerstheoutputsofthe1sthiddenlayeris h1 =ϕ1(W1x),
of thekth hidden layerhk =ϕk(Wkhk−1) and of the entire network isy =
ϕo(Wn+1hn). Typically layers share activation functions, possibly except
for the output layer. The three activation functions used in this project are
ReLU (Rectiﬁed Linear Unit), tanh and the linear functionf(x) =x. ReLU
is deﬁned as
ϕ(x) =
{
x if x≥ 0,
0 otherwise. (2.20)
Traininganeuralnetworkisdonebyupdatingtheweightmatricesusingerror
backpropagation and a speciﬁed loss function. The loss function represents
some quantity that the NN should minimize. A common example used in
supervised learning is the mean-square error (MSE), given by
L = 1
N
N∑
i=1
∥ˆy− y∥2
2, (2.21)
where y is the network’s output andˆy is the desired output. To perform the
error backpropagation an optimization method, often called an optimizer,
is used. In this project, Adam [Kingma and Ba, 2014] is used for baseline
training and Optimistic Adam [Daskalakis et al., 2017] is used for adversarial
training.
Deep Deterministic Policy Gradient (DDPG)
The full DDPG training scheme is presented in algorithm 1.
The DDPG is an actor-critic method using neural networks as the ac-
tor and the critic, speciﬁcally designed to handle continuous action spaces
19

--- PAGE 20 ---
Chapter 2. Theory
[Lillicrap et al., 2015]. The method utilizes two sets of actor/critic networks,
where one set is updated much slower and is called the target network. Dur-
ing training, the agent interacts with the environment through actions taken
by the actor. At each time-step the transition is saved in a replay buﬀerR
of ﬁnite size in the form of SARTS tuples:(si,ai,ri,ti,si+1), wheresi is the
observed state,ai is the action taken,ri is the reward, andti is 1 if the explo-
ration terminated and 0 if not, at timei. When updating the networks, these
tuples, sometimes called experiences or trajectories, are randomly sampled
in mini-batches.
The actor network is updated based on the assumption that the output
of the value network is continuously diﬀerentiable with respect to the ac-
tor network’s parameters. The expected returnJ = E[Q(s,µ (s|θµ)|θQ)] is
diﬀerentiated with respect toθµ using the chain rule:
∇θµJ = E[∇θµQ(s,µ (s|θµ)|θQ)]
= E[∇µQ(s,µ (s|θµ)|θQ)∇θµµ(s|θµ)]. (2.22)
Thus the loss function used is
Lµ
A =− 1
N
N∑
i=1
Q(si,µ (si|θµ)|θQ), (2.23)
where N is the number of samples in the mini-batch. The critic network
Q(s,a|θQ) is, as in Q-learning, updated using an MSE loss function
LQ
MSE = 1
N
N∑
i=1
(
yi−Q(si,ai|θQ)
)2
, (2.24)
where yi is given by the Bellman equation:
yi =ri +γQ′(si+1,µ′(si+1|θµ′
)|θQ′
)(1−ti), (2.25)
with Q′ and µ′ being the target critic and target actor respectively. The
parameters of the target networks are then updated asθ′←τθ + (1−τ)θ′,
with 0<τ ≪ 1.
In order to make the training more eﬃcient (and actually converge at all)
a demonstration system was implemented using ideas from [Nair et al., 2017]
and [Goecks et al., 2019]. A second replay buﬀerRd, called the demonstration
buﬀer, was initialized with state transitions performed by an "expert", in this
case the classical controller. A second loss function was added to the actor:
Lµ
BC = 1
2ND
ND∑
j=1
(
ad
j−µ(sd
j|θµ)
)2
cj, (2.26)
20

--- PAGE 21 ---
2.3 Reinforcement Learning controller
where sd
j and ad
j are states and actions from transitions inRd, and
cj =
{
1 if Q(sd
j,ad
j)>Q (sd
j,µ (sd
j)),
0 otherwise. (2.27)
cj exists to acknowledge that the demonstrations may not be perfect, so if
the agent determines that its own action is better then this portion of the
loss function will be discarded for that sample. During updating, 25% of
the samples are taken fromRd and 75% fromR. In addition, the agent is
pretrained using only expert demonstrations before it gets to explore the
environment. In the pretraining step,cj = 0 is used. Weight regularization
terms were also added to the loss functions of both actor and critic. The full
loss functions used were thus
Lµ =Lµ
A +Lµ
BC +Lµ
R =
− 1
N
N∑
i=1
Q(si,µ (si|θµ)|θQ) + 1
2ND
ND∑
j=1
(
ad
j−µ(sd
j|θµ)
)2
cj + 1
4∥θµ∥2
2,
LQ =LQ
MSE +LQ
R = 1
N
N∑
i=1
(
yi−Q(si,ai|θQ)
)2
+ 1
2
θQ2
2.
(2.28)
Projected Gradient Descent
Given a functionf(x), the projected gradient descent (PGD) method seeks
to minimizef using successive steps on the form
xt+1 = Πx+S
(
xt−α sgn(∇f(xt))
)
, (2.29)
where Πx+S signiﬁes projection onto a ball of some vector space centered
on x. If f is the loss function of some neural network, PGD can be used
as an eﬀective adversary by maximizingf. As presented in [Madry et al.,
2019], in the case of supervised learning, the loss function is of the form
f = L(θ,x,m (x)), withm(x) being the output of the networkm, and the
PGD step is
xt+1 = Πx+S
(
xt +α sgn(∇xtL(θ, xt,m (xt))
)
. (2.30)
Here,S is anl∞-ball of some sizeε >0. For Reinforcement Learning, and
speciﬁcally an actor-critic method, the objective is to perturb the state that
theactorisgiveninsuchawaythatittakesasuboptimalaction.Thefunction
to be minimized is the critic’s evaluation of the actor’s action,Q(s,µ (s)).
21

--- PAGE 22 ---
Chapter 2. Theory
Algorithm 1: DDPG training scheme with demonstrations
Data: Pre-training stepsL, number of episodesM, steps per
episode T, batch sizeN, exploration noise levelσ, Polyak
averaging constantτ.
Randomly initialize criticQ(s,a|θQ) and actorµ(s|θµ) with weights
θQ and θµ.
Initialize target networksQ′ andµ′ with weightsθQ′
←θQ,θµ′
←θµ.
Initialize replay buﬀerR and demonstration buﬀerRd with
trajectories from the expert.
for pre-training step = 1 ...Ldo
Randomly sample a minibatch ofN transitions
(sd
i,ad
i,rd
i,td
i,sd
i+1) fromRd.
Update critic networkQ by minimizing the lossLQ.
Update actor networkµ by minimizing the lossLµ.
Update target networks:
θQ′
←τθQ + (1−τ)θQ′
θµ′
←τθµ + (1−τ)θµ′
end
for episode = 1 ...M do
Reset environment.
Receive initial observation states1.
for k=1...T do
Select actionak =µ(sk|θµ) +Nk withNk∼N(0,σ 2).
Execute actionak, observe rewardrk, termination statustk
and new statesk+1.
Store transition (sk,ak,rk,tk,sk+1) inR.
Randomly sample a minibatch of0.75N transitions
(si,ai,ri,ti,si+1) fromR and 0.25N transitions
(sd
i,ad
i,rd
i,td
i,sd
i+1) fromRd.
Update critic networkQ by minimizing the lossLQ.
Update actor networkµ by minimizing the lossLµ.
Update target networks:
θQ′
←τθQ + (1−τ)θQ′
θµ′
←τθµ + (1−τ)θµ′
end
end
22

--- PAGE 23 ---
2.4 Lipschitz constants
Given an initial states0, ﬁnding an adversarial state to give the actor is
done with the following PGD step:
sk+1 = Πs0+S
(
sk−α sgn(∇skQ′(s0,µ (sk)))
)
. (2.31)
Again,S is an l∞-ball of some sizeε > 0. Typically in similar implemen-
tations, such as [Pattanaik et al., 2017], the target criticQ′ is used instead
of the behavior criticQ, which is what is done in this project. It should be
noted that in this project, the environment is a pendulum, and observations
of the pendulum angle are given in sine and cosine; while the state of the en-
vironment is (θ, ˙θ,φ, ˙φ), the observations given to the agent are on the form
(sinθ, cosθ, ˙θ,φ, ˙φ). Since logically the adversary should perturb the angle
itself, as opposed to the sine and cosine, the PGD algorithm is performed
on the state rather than the observation. The full PGD algorithm for the
pendulum is given in algorithm 2.
Algorithm 2: Projected Gradient Descent for the Furuta pendulum
Data: Initial statex0 = (θ0, ˙θ0,φ 0, ˙φ0), actor networkµ, target critic
networkQ′, ε, number of stepsn.
Set initial observation base on initial state:
s0← (sinθ0, cosθ0, ˙θ0,φ 0, ˙φ0)
x1←x0
Set step length:α← 2.5ε/n
for k = 1...n do
Set current observation based on current state:
sk← (sinθk, cosθk, ˙θk,φk, ˙φk)
Take one (non-projected) step:
xk+1←xk−α sgn
(
∇xkQ′(s0,µ (sk|θµ)|θQ′
)
)
Project ontol∞-ball: xk+1← clamp(xk+1,x 0−ε1,x 0 +ε1)
end
The adversarial training was performed by perturbing the observation
given to the actor when it takes actions during exploration. The training
scheme using this method is described in algorithm 3.
2.4 Lipschitz constants
A Lipschitz constantL for a functionf, deﬁned onΩ, is deﬁned by
infL> 0 s.t. ∥f(x)−f(y)∥2≤L∥x− y∥2,∀x, y∈ Ω. (2.32)
In essence,L is a measure of how quickly the function value can vary; it is
often called a smoothness constant. In robust control, the Lipschitz constant
23

--- PAGE 24 ---
Chapter 2. Theory
Algorithm 3: Adversarial DDPG training using PGD
Data: Trained DDPG agent with networksµ,Q,µ′,Q′, number of
episodes M, steps per episodeT, batch sizeN, Polyak
averaging constantτ, ε, number of PGD stepsn.
Initialize replay buﬀerR and demonstration buﬀerRd with
trajectories from the expert.
for episode = 1 ...M do
Reset environment.
for k=1...T do
Receive current statexk.
Perturb current state:˜xk←PGD (xk,µ,Q′,ε,n ).
Set ˜sk = (sin ˜θk, cos ˜θk, ˜˙θ, ˜φ, ˜˙φ).
Select actionak =µ(˜sk|θµ) +Nk withNk∼N(0,σ 2).
Execute actionak, observe rewardrk, termination statustk
and new statesk+1.
Store transition (˜sk,ak,rk,tk,sk+1) inR.
Randomly sample a minibatch of0.75N transitions
(˜si,ai,ri,ti,si+1) fromR and 0.25N transitions
(sd
i,ad
i,rd
i,td
i,sd
i+1) fromRd.
Update critic networkQ by minimizing the lossLQ.
Update actor networkµ by minimizing the lossLµ.
Update target networks:
θQ′
←τθQ + (1−τ)θQ′
θµ′
←τθµ + (1−τ)θµ′
end
end
is a tool for estimating how robust a controller is, particularly against mea-
surement noise. The idea is that a controller with a small Lipschitz constant
will produce small variations in control output as a response to a varying
measurement input, and thus not be aﬀected as much by the noise. [Fazlyab
et al., 2019] recently proposed a method to estimate the Lipschitz constant
of a neural network. This allows us to in theory evaluate the robustness of a
neural network controller. The estimation method is summarized here: As-
suming all activation functions in a network are the same, a neural network
model can be written compactly as
Bx =ϕ(Ax + b) and f(x) = Cx + bl, (2.33)
24

--- PAGE 25 ---
2.4 Lipschitz constants
where x = [x0⊤
x1⊤
... xl⊤
]⊤ is the concatenation of the input and the ac-
tivation values of the network’s layers and the matricesA, B, C and b are
given by
A =


W0 0 ... 0 0
0 W1 ... 0 0
... ... ... ... ...
0 0 ... Wl−1 0


, B =


0 In1 0 ... 0
0 0 In2 ... 0
... ... ... ... ...
0 0 0 ... Inl


,
C =
[
0 ... 0 Wl
]
, b =
[
b0⊤
... bl−1⊤
]⊤
.
(2.34)
In addition, deﬁne the setTn as
Tn ={T∈ Sn|T =
n∑
t=1
λiieie⊤
i +
∑
1≤i<j≤n
λij(ei− ej)(ei− ej)⊤,λij≥ 0},
(2.35)
where Sn is the set of n-by-n symmetric matrices, and ei are unit basis
vectors. With this, the Lipschitz constant of the network can be estimated
using the following theorem:
Theorem 2.2. Consider anl-layer fully connected neural network. Letn =∑l
k=1nk be the total number of hidden neurons and suppose the activation
functions are slope-restriced in the sector[α,β ]. DeﬁneTn as in(2.35). Deﬁne
A and B as in(2.34). Consider the matrix inequality
M(ρ, T) =
[
A
B
]⊤[
−2αβT (α +β)T
(α +β)T −2T
][
A
B
]
+


−ρIn0 0 ... 0
0 0 ... 0
... ... ... ...
0 0 ... (Wl)⊤Wl


⪯ 0.
(2.36)
If (2.36) is satisﬁed for some(ρ, T)∈ R+×Tn, then
∥f(x)−f(y)∥2≤√ρ∥x− y∥2,∀x, y∈ Rn0. (2.37)
In other words,√ρ is a bound on the network’s Lipschitz constant, and
ρ is given by solving the SDP (2.36). It should be noted that the ReLU
activation function is slope-restricted on[0, 1] which here givesα = 0,β = 1.
The method can be adapted by making assumptions on the setTn. As each
λij is a decision variable, in the base case the variable complexity isO(n2).
[Fazlyab et al., 2019] refers to this method asLipSDP-Network, and lists
two alternatives.
25

--- PAGE 26 ---
Chapter 2. Theory
LipSDP-Neuron ignores cross-coupling of neurons and sets T =
diag(λ11,...,λ nn). This gives a variable complexity ofO(n).
LipSDP-Layer considers only one constrain per layer, setting T =
blkdiag(λ1In1,...,λ lTnl). This gives a variable complexity ofO(l).
As solving SDPs typically has a computational complexity scaling with
decision variables asO(n3) in the best case, andO(n6) in the worst case,
keeping variable complexity low is desirable. In this project, theLipSDP-
Neuron variant is used.
When solving this problem in Julia, it appeared that Julia’s front-end
interface for optimization, JuMP, was unable to exploit the sparsity in the
problem, leading to untenable computation times and memory requirements.
Instead, the problem was solved using Mosek’s back-end Julia implementa-
tion, which required the problem to be formulated on a standard form. This
reformulation is presented in Appendix A.
26

--- PAGE 27 ---
3
Method
In this section the methodology for training and evaluating the classiﬁers and
agents is described.
All code used is available athttps://github.com/polhager/FurutaRL.
Computational setup
All training and experiments in this project were conducted using a Ryzen
5 3600 CPU (6 cores, 12 threads), 16GB of RAM and a NVIDIA 2070 Su-
per GPU with 8GB of VRAM. Training was performed on the GPU where
possible. Julia was the programming language used, and MOSEK was used
to solve the Lipschitz SDP.
3.1 MNIST
A neural network with the structure given in Table 3.1 was trained on a set
of 60 000 images from the MNIST set. A set of 10 000 images was used as the
testing set. The resolution of the images are 28x28, and so the inputs to the
network are of size282 = 784. The output is a vector of length 10 containing
the probability that the input image contains each digit (0-9). The network
was trained for 10 epochs with a batch size of 16. The network structure was
chosen because it is similar to the networks tested in [Fazlyab et al., 2019],
and it achieved a high accuracy on the unperturbed test set (0.974).
To visualize the eﬀectiveness of PGD as an adversary compared to white
noise, the accuracy of the baseline model was evaluated on the test set per-
turbed by Gaussian zero-mean noise with standard deviationsσ∈ [0.0, 0.1],
as well as by PGD withε∈ [0.0, 0.2]. Since for Gaussian distributions, 95%
of samples lie within±2σ, usingε = 2σ gives roughly the same interval of
possible perturbed values, and thus somewhat comparable disturbance lev-
els. It should be noted that Gaussian noise is not used at all during training
and only during testing, and PGD is only used during training and not dur-
27

--- PAGE 28 ---
Chapter 3. Method
Table 3.1: Network structure for the classiﬁer used in the MNIST experiment.
layer neurons activation function
input 784 -
1 100 ReLU
2 100 ReLU
3 10 Softmax
ing testing. This comparison is only here to get an idea of how potent PGD
potentially is.
The baseline model was then subject to diﬀerent levels of adversarial
training. It was trained for another 10 epochs with the training set perturbed
by a PGD adversary, with the diﬀerent values ofε∈{ 0.01, 0.05, 0.1, 0.15}. All
classiﬁers were evaluated by perturbing the test set with Gaussian zero-mean
noise with standard deviationsσ∈ [0.0, 2.0]. The accuracy of each model for
eachσ wasrecordedandplottedagainst σ.Inaddition,theLipschitzconstant
of each model was estimated.
3.2 Furuta pendulum
Environment
Most of the training and testing was done in a simulated environment. The
environment implements the state-space system deﬁned in (2.3) and solves it
using the Runge-Kutta method RK3/8, with a sample time of 0.006s. This
sample time was chosen since it is the eﬀective sample time of the physical
process.ParametervaluescanbefoundinTable3.2. τC andτS weremanually
estimated, max input and dt were chosen, and other values were given by
[Katz, 2019].
28

--- PAGE 29 ---
3.2 Furuta pendulum
Table 3.2: Parameter values for the Furuta pendulum model.
quantity value
J [kg·m2] 0.000154
M [kg] 0.0
ma [kg] 0.0
mp [kg] 0.00544
la [m] 0.0430
lp [m] 0.0646
τC [Nm] 0.0076
τS [Nm] 0.0080
max input [a.u.] 0.04
dt [s] 0.006
The reward function used for the environment was
R(x,u ) =−5θ2− 0.05 ˙θ2−φ2− 0.05 ˙φ2− 0.05u2− 10000(|φ|> 2π). (3.1)
The classical controller used was given by
u =



[
0.8139 0 .0541 0 .0226 0 .0258
]
x +uF if|θ|< 0.5,| ˙θ|< 5,
0.04
˙θ cosθ
(
cosθ− 1 +
˙θ2
2ω2
0
)
10 +
⏐⏐⏐ ˙θ cosθ
(
cosθ− 1 +
˙θ2
2ω2
0
)⏐⏐⏐
otherwise,
(3.2)
with uF given by equation (2.7). The linear part is an LQR controller with
weight matrices
Q =


100 0 0 0
0 1 0 0
0 0 10 0
0 0 0 10

, R = 100, N = 0, (3.3)
and the nonlinear part is simply equation (2.17) withK = 0.04, b = 10.
Training
The baseline agent was trained on a simulated process using the demonstra-
tion implementation described in algorithm 1. The total loss functions used
are restated here: for the actor
Lµ =Lµ
A +Lµ
BC +Lµ
R, (3.4)
29

--- PAGE 30 ---
Chapter 3. Method
with



Lµ
A =− 1
N
N∑
i=1
Q(si,µ (si|θµ)|θQ),
Lµ
BC = 1
2ND
ND∑
j=1
(
ad
j−µ(sd
j|θµ)
)2
cj,
Lµ
R = 1
4∥θµ∥2
2,
(3.5)
and for the critic
LQ =LQ
MSE +LQ
R, (3.6)
with



LQ
MSE = 1
N
N∑
i=1
(
ri +γQ′(si+1,µ′(si+1|θµ′
)|θQ′
)(1−ti)−Q(si,ai|θQ)
)2
,
LQ
R = 1
2
θQ2
2.
(3.7)
The network structures of the actor and critic are given in Tables 3.3 and 3.4
respectively. The network structures were chosen because they are similar to
the DQN used in [Wilroth et al., 2020], which successfully performed swing-
up of a Furuta pendulum. Training hyperparameters are given in Table 3.5.
It should be noted that the exploration noise is the standard deviation of the
Gaussian noise applied to the action, and the action is scaled to be limited
to [−1.0, 1.0].
Table 3.3: Network structure for the actor used for the Furuta pendulum.
layer neurons activation function
input 5 -
1 24 ReLU
2 48 ReLU
3 72 ReLU
4 96 ReLU
5 128 ReLU
6 1 tanh
30

--- PAGE 31 ---
3.2 Furuta pendulum
Table 3.4: Network structure for the critic used for the Furuta pendulum.
layer neurons activation function
input 6 -
1 24 ReLU
2 48 ReLU
3 72 ReLU
4 96 ReLU
5 128 ReLU
6 1 linear
Table 3.5: Training hyperparameters for the Furuta agents.
parameter value
batch size 256
γ 0.99
τ 0.995
exploration noise 0.1
buﬀer size 100000
expert buﬀer size 50000
The baseline agent was trained in three steps. First it was pretrained using
only expert demonstrations for 35000 steps. Secondly it was trained until
it attained an average reward over ﬁve episodes of -3500 or greater. Each
episode was terminated if|φ| exceeded 2π, the pendulum had|θ|≤ 0.05,
| ˙θ|≤ 0.5, or after ﬁve seconds. This eﬀectively served to teach the agent
to swing up and catch the pendulum. Finally it was trained the same way
as in step two, except the episodes only terminated if|φ|≥ 2π or after ﬁve
seconds. This trained the agent to swing up, catch and balance the pendulum.
Dividing the ﬁnal two steps like this was found to be more eﬀective.
The baseline agent was further trained using PGD according to algorithm
3. For eachε∈{ 0.025, 0.05, 0.075, 0.1, 0.125, 0.15}, ﬁve agents were trained
until their average reward over ﬁve episodes exceeded -10000. Agents that
failed to swing-up or balance an unperturbed pendulum, or exceeded 400
episodes, were discarded and retrained.
31

--- PAGE 32 ---
Chapter 3. Method
Testing and evaluation
Theagentsweretestedusingthefollowingtest:anagentperformsoneepisode
of swing-up and balancing on the environment. After half the episode, if the
pendulum angle drops below π/2 in either direction, the test is failed. If
not, the test is successful. During the episode, the states given to the agent
are perturbed with Gaussian zero-mean noise with standard deviationsσ∈
[0.0, 0.3]. This test is carried out 30 times for each agent at each noise level,
with the number of successful tests recorded. Results are then collected for all
agents of the same level of PGD-training, and the fraction of successful test
of each training level is plotted againstσ. In addition, the Lipschitz constants
of each actor network was estimated. The means and standard deviations of
the constants of the ﬁve agents for each PGD-level were calculated.
32

--- PAGE 33 ---
4
Results
In this section results from the experiments are presented. First the eﬀect
of PGD training on the MNIST classiﬁer is shown, followed by correspond-
ing results for the RL agents on the Furuta pendulum. Results consist of a
comparison of the strength of PGD and Gaussian noise, the eﬀect of PGD
training on robustness performance, as well as a comparison between robust-
ness and Lipschitz constant.
Certain numerical problems were encountered in this project, aﬀecting
some of the results. For MNIST, running the PGD algorithm against the
baselinemodelwith ε≥ 0.35orattemptingPGDtrainingwith ε≥ 0.16,Julia
reported a NaN error. This occurred when running in a Jupyter notebook,
but not in the Atom IDE.
For the Furuta pendulum, running the PGD algorithm against the base-
line agent withε≥ 0.34 resulted in the algorithm returning NaN states at
some point, which interestingly caused the pendulum’s angle measurements
tobesettoeither0orapproximately1.347.Inaddition,duringPGD-training
of an agent withε≥ 0.125 a NaN would appear somewhere, causing every
weight in the neural networks to be set to NaN, ruining this agent. This
became more frequent with higherε, and training an agent withε≥ 0.175
was impossible for this reason.
4.1 MNIST
Figure 4.1 shows the accuracy of the baseline classiﬁer on the test set per-
turbed by PGD withε∈ [0.0, 0.2] and white noise withσ∈ [0.0, 0.1]. The
accuracy atε = 0.2 was 0.0041, and the accuracy atσ = 0.1 was 0.97.
33

--- PAGE 34 ---
Chapter 4. Results
Figure 4.1: The accuracy of the baseline classiﬁer when perturbed by PGD
(blue) and white noise (red).
Figure 4.2 shows one sample of the MNIST data set together with the same
sample perturbed by Gaussian zero-mean noise with standard deviationσ =
0.1, and by PGD against the baseline classiﬁer withε = 0.2. The baseline
model classiﬁed the unperturbed and the Gaussian noise samples as 5, and
the PGD sample as 3.
(a) Unperturbed
 (b) White noise, σ = 0.1
 (c) PGD, ε = 0.2
Figure 4.2: A sample from the MNIST dataset, with diﬀerent perturbations.
The baseline model classiﬁes (a) and (b) as 5, and (c) as 3.
Figure 4.3 shows the accuracy of the baseline MNIST classiﬁer as well as
34

--- PAGE 35 ---
4.1 MNIST
the PGD-trained ones when tested on the test set perturbed by zero-mean
Gaussian noise with varying standard deviations.
Figure 4.3: The accuracy of the MNIST models on the test set perturbed by
white noise.
Table 4.1 shows the estimated Lipschitz constants for the MNIST classiﬁer
networks, as well as a performance metric, which is simply the mean accuracy
of each model in Figure 4.3.
Table 4.1: Lipschitz constants of MNIST classiﬁers with diﬀerent levels of
PGD training.
PGD level Lipschitz constant performance
baseline 279.88 0.5050
0.01 233.10 0.6239
0.05 81.09 0.6865
0.10 138.91 0.7242
0.15 223.34 0.7166
35

--- PAGE 36 ---
Chapter 4. Results
4.2 Furuta pendulum
Figure 4.4 shows the success rate of the baseline Furuta agent when fed
states perturbed by zero-mean Gaussian noise withσ∈ [0, 0.4] and PGD
with ε∈ [0, 0.8]. The success rate is the average over 30 experiments. For
all PGD data points marked with crosses, the PGD algorithm returned NaN
at some point. As previously mentioned, this caused the pendulum angle
measurements to be set to 0 or 1.347, which would pass the test. For this
reason, crossed out points that show successful tests (1) should be considered
false positives, and those showing failed tests (0) had already failed before
the NaN appeared and should be considered true negatives.
Figure 4.4: Success rate of the baseline Furuta agent when perturbed by PGD
and white noise.
Figure 4.5 shows the average success rates of the ﬁve PGD-trained agents
at each PGD level when performing the robustness test, plotted against the
noise level. Also shown are the success rates for the classical controller and
the baseline agent. Figure 4.6 shows the success rates of the best performing
PGD-trained agents at each level, as well as the classical controller and the
baseline agent.
36

--- PAGE 37 ---
4.2 Furuta pendulum
Figure 4.5: Average success rates of the PGD-trained agents, along with the
baseline agent and the classical controller.
Figure 4.6: Success rates of the best performing PGD-trained agents, along
with the baseline agent and the classical controller.
37

--- PAGE 38 ---
Chapter 4. Results
Figure 4.7 shows the average success rates of each agent plotted against their
Lipschitz constants. The average success rate here means the average value
of curves like the ones plotted in Figures 4.5 and 4.6. A table containing all
values along with means and standard deviations per PGD level can be found
in Appendix B.
Figure 4.7: The relation between the Lipschitz constants and success rates of
every PGD-trained Furuta agent.
Appendix C contains plots from simulations of the Furuta pendulum, with
various controllers and adversaries.
38

--- PAGE 39 ---
5
Discussion and Conclusion
5.1 MNIST
Figures 4.1 and 4.2 clearly demonstrate the potency of PGD as an adversary
when applied to the MNIST dataset. The accuracy of the model on adver-
sarial samples deteriorates very quickly when exposed to PGD, and barely at
all the subject to similar levels of white noise, as seen in Figure 4.1. Figure
4.2 shows a typical adversarial example: the PGD disturbed sample is clearly
still a 5 to a human eye, but the model classiﬁes it as a 3. We also see that
the PGD adversary pushes most of the pixels to their extreme permitted val-
ues; most of the background pixels are grey, which corresponds to the PGD
algorithm changing their values from 0 to 0.2, which is the upper limit given
ε = 0.2. This makes sense, and indicates that the loss function has a max-
imum where most pixels are perturbed by more than 0.2. The white noise
example, as expected, has more randomly distributed perturbations. This
tells us that whileε = 2σ guarantees that 95% of the random disturbances
fall within the same interval as the PGD disturbances, the PGD adversary
likely has a higher average disturbance, which means thatε = 2σ might not
be an entirely fair comparison of disturbance levels. Constructing a more
fair comparison would however be diﬃcult and ultimately not very useful,
since the conclusions will be based on using PGD for robustness training
and Gaussian noise for evaluation, which means there is no real need for a
comparison between the two disturbance models.
The PGD training does improve model robustness to white noise, as
shown in Figure 4.3. The baseline model performed the worst, and models
with higher PGD levels performed better, except forε = 0.15, which per-
formed similarly (or slightly worse, as shown in Table 4.1) toε = 0.1. This
indicates that there is an upper limit to the adversarial training, beyond
which returns diminish or even deteriorate.
What is interesting is the fact that higher model robustness does not
seem to correlate with lower Lipschitz constants, as claimed in [Fazlyab et
al., 2019]. Table 4.1 shows that while the baseline model does have the worst
39

--- PAGE 40 ---
Chapter 5. Discussion and Conclusion
performanceandthehighestLipschitzconstant,the0.05modelhasthelowest
Lipschitz constant but not the best performance, and the 0.10 model has the
best performance but a higher Lipschitz constant. Also, 0.10 and 0.15 show
similar performances but greatly diﬀering constants. This indicates that this
Lipschitz constant might not be an ideal representation of robustness for
neural networks. One reason for this is that the input values are limited;
for the MNIST dataset, all pixel values are between 0 and 1. On the other
hand, the Lipschitz estimation considers any possible input values which
can technically be fed to the network, but do not appear in any data even
actually given to the network. A better metric might be given by a "local"
estimation of the Lipschitz constant which considers a restricted input space.
It is interesting to note that [Fazlyab et al., 2019] shows decreasing Lipschitz
constants for the baseline model,ε = 0.01 and ε = 0.05 in a similar test,
which is corroborated by our results. The trend does not continue however.
5.2 Furuta pendulum
Attempting to compare the strengths of PGD and Gaussian noise as ad-
versaries in the same way as for MNIST resulted in Figure 4.4, which is
not as simple to interpret. Firstly, the numerical issues with NaNs appear-
ing made much of the PGD data unreliable. As previously discussed, this
NaN phenomenon caused the pendulum angle to be set to either 0 or 1.347,
which would evaluate as passing the test. This is why most of the crossed
out points show passed tests. The ones that show failed tests simply mean
that the agent failed the test before the NaN appeared. Secondly, the PGD
results were binary, showing either 30 successful tests or 30 failed ones. This
is explained by the fact that the PGD algorithm, the DDPG agent and the
Furuta pendulum environment are all deterministic. Without artiﬁcially in-
troducing randomness, this means that for a certain agent, a certainε and a
certain initial pendulum angle, the result will always be identical.
Usingε = 2σ as roughly equivalent noise levels, PGD impacts the success
rate of the agent at a lower threshold than Gaussian noise, lending some
credence to the idea that it is a potent adversary. Drawing any conclusions
beyond this is diﬃcult however.
The eﬀectiveness of the PGD training did not meet expectations. Figure
4.5 shows that the average eﬀectiveness of the ﬁve agents at each PGD level
was worse than the baseline agent at every level. This can be attributed to
a number of things, but likely the chief culprit is the inherent instability of
Reinforcement Learning. Even training the baseline agent, the agent’s per-
formance would wildly peak and trough during training, often losing and
regaining the ability to balance the pendulum multiple times. For this rea-
son, choosing when to halt training was not trivial. The baseline agent was
40

--- PAGE 41 ---
5.2 Furuta pendulum
stopped when it reached an average reward over ﬁve episodes of -3500 or
higher. Most agents during PGD training, at allε, would simply never reach
this value. The PGD adversary works by fooling the agent into reducing its
returned reward, so it is natural that this would cause agents to reach lower
best rewards. Simply training the agents for a certain number of episodes
was also not feasible, since most of the time this would halt the agent at a
point where it could not perform balancing even for an unperturbed pendu-
lum, so the agent would have to be discarded. Since training took around
45 minutes per 100 episodes, this was simply too time ineﬃcient, and also
did not guarantee better agents. Finding the best stopping criterion could be
a subject of further research, and would likely heavily contribute towards a
more eﬀective training process.
Another factor that potentially contributes is the actual eﬀectiveness of
the PGD algorithm as an adversary. As previously shown, evaluating the
algorithm’s eﬀectiveness proved quite diﬃcult. It also depends heavily on the
accuracy of the agent’s critic network, which itself changes during training.
It is possible, though diﬃcult to demonstrate, that since the actor, critic and
adversary all depend on each other during training, they derail and start
behaving strangely. This further plays into the instability of RL training.
Looking at Figure 4.6, we see that the best performing agents come close
to the baseline agent, with one even outperforming it. It is diﬃcult to say
whether this is due to the PGD training or simply luck given the instability
of the training process. This result does however indicate that there may
be some promise here, and further testing, hyperparameter tuning and the
like may lead to better reproducible results. This could be an area of further
research.
Ignoring the diﬀerence between the PGD agents and the baseline, the
PGD agents do not seem to improve with higherε. Aside fromε = 0.1 per-
forming slightly better on average, and one agent atε = 0.075 signiﬁcantly
outperforming every other agent, all PGD levels are very close with no ap-
parent order. This further supports the notion that PGD training did not
have a noticeable eﬀect on robustness. Again, however, we cannot discard
the possibility that it could with further investigation and ﬁne-tuning.
Figure 4.7 reveals no apparent correlation between lower Lipschitz con-
stants and higher performance levels, contrary to expectation. There could
possibly be a correlation between lower Lipschitz constants and worse per-
formance, however that is neither very clear nor what we are interested in.
This further reinforces the notion that the Lipschitz constant is not an ideal
measure of neural network robustness, for the same reasons as previously dis-
cussed. Since observations contain sine and cosine functions which are limited
to [−1, 1], as well as angle velocities which have a practical upper bound, the
input space is restricted, similar to the MNIST case. Again, a better measure
might be one that only considers this limited input space. Designing such a
41

--- PAGE 42 ---
Chapter 5. Discussion and Conclusion
measure is an interesting topic for future research.
5.3 Conclusions
PGD training did positively inﬂuence the robustness of the MNIST classiﬁer,
although neither PGD training nor robustness seem to correlate with the
Lipschitz constants, contrary to the claims in [Fazlyab et al., 2019]. For the
Furuta pendulum, there is no evidence that PGD training positively aﬀected
the robustness or the Lipschitz constants of the RL controllers, although we
cannot discard the possibility that it could, given a more ﬁnely tuned training
process. There is also no evidence of a correlation between robustness and the
Lipschitz constant. In summary, expectations are mostly met for the simple
MNIST case, but more investigation is needed for the more complicated RL
case.
Possible future work includes designing a more local robustness measure,
ﬁne-tuning the adversarial training process and exploring the impact of the
agents’ network structures. One could also investigate other types of robust-
ness, as this project only looked at robustness towards white measurement
noise.
42

--- PAGE 43 ---
Bibliography
Daskalakis, C., A. Ilyas, V. Syrgkanis, and H. Zeng (2017). “Training gans
with optimism”.CoRR abs/1711.00141.
Fazlyab, M., A. Robey, H. Hassani, M. Morari, and G. J. Pappas (2019).
“Eﬃcient and accurate estimation of lipschitz constants for deep neural
networks”.CoRR abs/1906.04893.
Furuta, K., M. Yamakita, S. Kobayashi, and M. Nishimura (1991). “A new
inverted pendulum apparatus for education”. In: KHEIR, N. et al. (Eds.).
Advances in Control Education 1991. Pergamon, Amsterdam, pp. 133–
138.
Gäfvert, M. (1998). Modelling the Furuta Pendulum. Tech. rep. Technical
Reports TFRT-7574. Lund University, Department of Automatic Control.
Goecks, V. G., G. M. Gremillion, V. J. Lawhern, J. Valasek, and N. R.
Waytowich (2019). “Integrating behavior cloning and reinforcement learn-
ing for improved performance in sparse reward environments”.CoRR
abs/1910.04281.
Goodfellow, I. J., J. Shlens, and C. Szegedy (2015). “Explaining and harness-
ing adversarial examples”.
Huang, S. H., N. Papernot, I. J. Goodfellow, Y. Duan, and P. Abbeel
(2017). “Adversarial attacks on neural network policies”. CoRR
abs/1702.02284.
Katz, B. (2019).Furuta pendulum. Unpublished.
Kingma, D. P. and J. Ba (2014). “Adam: a method for stochastic optimiza-
tion”.CoRR abs/1412.6980.
Krizhevsky, A. (2009).Learning Multiple Layers of Features from Tiny Im-
ages. Tech. rep.
LeCun, Y. and C. Cortes (2010). “MNIST handwritten digit database”.
Lillicrap, T. P., J. J. Hunt, A. Pritzel, N. Heess, T. Erez, Y. Tassa, D. Silver,
and D. Wierstra (2015). “Continuous control with deep reinforcement
learning”.
43

--- PAGE 44 ---
Bibliography
Madry, A., A. Makelov, L. Schmidt, D. Tsipras, and A. Vladu (2019). “To-
wards deep learning models resistant to adversarial attacks”.
Mnih, V., K. Kavukcuoglu, D. Silver, A. Graves, I. Antonoglou, D. Wier-
stra, and M. A. Riedmiller (2013). “Playing atari with deep reinforcement
learning”.CoRR abs/1312.5602.
MOSEK (2021).Mosek modeling cookbook. url: https://docs.mosek.com/
MOSEKModelingCookbook-letter.pdf.
Nair, A., B. McGrew, M. Andrychowicz, W. Zaremba, and P. Abbeel (2017).
“Overcoming exploration in reinforcement learning with demonstrations”.
CoRR abs/1709.10089.
Oikarinen, T. P., T.-W. Weng, and L. Daniel (2020). “Robust deep reinforce-
ment learning through adversarial loss”.CoRR abs/2008.01976.
Pattanaik, A., Z. Tang, S. Liu, G. Bommannan, and G. Chowdhary (2017).
“Robust deep reinforcement learning with adversarial attacks”.CoRR
abs/1712.03632.
Wilroth, J., J. Hansson, and L. Hassbring (2020).Regulating the furuta pen-
dulum. Course project report at LTH.
44

--- PAGE 45 ---
A
MOSEK formulation of
Lipschitz SDP
The Julia implementation of MOSEK takes SDPs on the form
min ⟨¯C1, Z1⟩ +... ⟨¯Cm, Zm⟩ + c⊤z
s.t.


⟨¯ a1, Z⟩
...
⟨¯ an, Z⟩

 + Az = b,
Z⪰ 0.
(A.1)
We will aim to rewrite (2.36) on this form. Withα = 0,β = 1 we get
[
A
B
]⊤[
−2αβT (α +β)T
(α +β)T −2T
][
A
B
]
=
[
A
B
]⊤[
0 T
T −2T
][
A
B
]
= B⊤TA+ A⊤TB− 2B⊤TB.
(A.2)
Assuming T = diag{λi}i=1,...n, we can decompose this matrix into
B⊤TA+ A⊤TB− 2B⊤TB =
n∑
i=1
Viλi, (A.3)
where each Vi is determined by settingλi = 1 and λj = 0,i ̸= j in T.
Additionally deﬁne
V0 =


−In0 0 ...
0 0 ...
... ... ...

. (A.4)
45

--- PAGE 46 ---
Appendix A. MOSEK formulation of Lipschitz SDP
Now deﬁnex = [ρ,λ 1,...,λ n]⊤, and
W =


0 ... 0
... ... ...
0 ... (Wl)⊤Wl

. (A.5)
M(ρ, T) can now be written as
M(ρ, T) = W +
n∑
0=1
Vixi. (A.6)
The constraintM(ρ, T)⪯ 0 ⇐⇒ −M(ρ, T)⪰ 0 can now be expressed as
A0 +
n+1∑
i=1
Aixi⪰ 0, (A.7)
where A0 =−W, Ai =−Vi−1,i > 0. This lets us write the optimization
problem as
min c⊤x
s.t. A0 +
n+1∑
i=1
Aixi = X,
X⪰ 0.
(A.8)
The dual to this problem is [MOSEK, 2021]
max −⟨ A0, Z⟩
s.t. ⟨Ai, Z⟩ =ci, i = 1,...,n + 1,
Z⪰ 0,
(A.9)
which is on the desired form. The value ofρ, which is what is interesting,
is simply given by the ﬁrst element of−⟨A0,Z⟩, since the primal and dual
have the same objective value at optimality. Reformulating (A.9) with our
original variable names gives
max ⟨W, Z⟩
s.t. −⟨ Vi−1, Z⟩ =ci, i = 1,...,n + 1,
Z⪰ 0.
(A.10)
46

--- PAGE 47 ---
B
Table of Furuta results
This Figure contains the Lipschitz constants and average success rates of
every PGD-trained Furuta agent. Means and standard deviations for each
PGD level are also given. The best (lowest) Lipschitz constant and best
(highest) performance at each level is highlighted.
Table B.1: Lipschitz constants and performance scores for PGD-trained Fu-
ruta agents.
Lipschitz mean std performance mean std
baseline 36.10 0.6527
ε = 0.025
1 52.10 0.5101
2 50.01 0.6344
3 30.46 46.91 12.86 0.5645 0.4619 0.1571
4 38.34 0.2570
5 63.66 0.3430
ε = 0.050
1 29.05 0.2882
2 33.57 0.5570
3 61.80 39.79 14.14 0.3688 0.4680 0.1371
4 45.88 0.5032
5 28.65 0.6226
ε = 0.075
1 46.60 0.3860
2 43.16 0.7301
3 63.78 54.59 9.15 0.1355 0.4385 0.2251
4 45.88 0.3677
47

--- PAGE 48 ---
Appendix B. Table of Furuta results
5 28.65 0.5731
ε = 0.100
1 36.89 0.5849
2 35.79 0.6430
3 55.74 40.52 11.38 0.6140 0.5759 0.0566
4 47.75 0.5075
5 26.44 0.5301
ε = 0.125
1 52.37 0.5602
2 38.95 0.5871
3 49.87 43.24 7.32 0.2914 0.4824 0.1158
4 38.67 0.4935
5 36.33 0.4796
ε = 0.150
1 42.83 0.5882
2 21.84 0.5806
3 71.04 43.98 19.89 0.1215 0.4430 0.1927
4 55.36 0.4580
5 28.83 0.4785
48

--- PAGE 49 ---
C
Furuta pendulum plots
The following ﬁgures show sample simulations of the Furuta pendulum con-
trolled by the classical controller, baseline agent,ε = 0.075 agent 2 (the best
performing agent) andε = 0.15 agent 3 (the worst performing agent), with
various adversaries.
(a) Pendulum angle
 (b) Control signal
Figure C.1: The classical controller with unperturbed states.
(a) Pendulum angle
 (b) Control signal
Figure C.2: The baseline agent with unperturbed states.
49

--- PAGE 50 ---
Appendix C. Furuta pendulum plots
(a) Pendulum angle
 (b) Control signal
Figure C.3: Theε = 0.075 agent 2 with unperturbed states.
(a) Pendulum angle
 (b) Control signal
Figure C.4: Theε = 0.15 agent 3 with unperturbed states.
(a) Pendulum angle
 (b) Control signal
Figure C.5: The classical controller with states perturbed by Gaussian noise,
σ = 0.2.
50

--- PAGE 51 ---
Appendix C. Furuta pendulum plots
(a) Pendulum angle
 (b) Control signal
Figure C.6: The baseline agent with states perturbed by Gaussian noise,
σ = 0.2.
(a) Pendulum angle
 (b) Control signal
Figure C.7: Theε = 0.075 agent 2 with states perturbed by Gaussian noise,
σ = 0.2.
(a) Pendulum angle
 (b) Control signal
Figure C.8: Theε = 0.15 agent 3 with states perturbed by Gaussian noise,
σ = 0.2.
51

--- PAGE 52 ---
Appendix C. Furuta pendulum plots
(a) Pendulum angle
 (b) Control signal
Figure C.9: The baseline agent with states perturbed by PGD,ε = 0.2.
(a) Pendulum angle
 (b) Control signal
Figure C.10: Theε = 0.075 agent 2 with states perturbed by PGD,ε = 0.2.
(a) Pendulum angle
 (b) Control signal
Figure C.11: Theε = 0.15 agent 3 with states perturbed by PGD,ε = 0.2.
52

--- PAGE 53 ---
Appendix C. Furuta pendulum plots
(a) Pendulum angle
 (b) Control signal
Figure C.12: The baseline agent with states perturbed by PGD,ε = 0.36.
After approx. 1.7 seconds a NaN appears.
(a) Pendulum angle
 (b) Control signal
Figure C.13: Theε = 0.075 agent 2 with states perturbed by PGD,ε = 0.36.
(a) Pendulum angle
 (b) Control signal
Figure C.14: Theε = 0.15 agent 3 with states perturbed by PGD,ε = 0.36.
53

--- PAGE 54 ---

--- PAGE 55 ---

/XQG8QLYHUVLW\
'HSDUWPHQWRI$XWRPDWLF&RQWURO
%R[
6(/XQG6ZHGHQ
Document name 
0$67(5¶67+(6,6
Date of issue 
2FWREHU
Document Number 
7)57
Author(s) 
3KLOLS2OKDJHU
Supervisor 
-RKDQ*U|QTYLVW'HSWRI$XWRPDWLF&RQWURO/XQG
8QLYHUVLW\6ZHGHQ
5LFKDUG3DWHV'HSWRI$XWRPDWLF&RQWURO/XQG
8QLYHUVLW\6ZHGHQ
$QGHUV5DQW]HU'HSWRI$XWRPDWLF&RQWURO/XQG
8QLYHUVLW\6ZHGHQ
H[DPLQHU

Title and subtitle 
5REXVW5HLQIRUFHPHQW/HDUQLQJ&RQWURORID)XUXWD3HQGXOXP
Abstract 

7KHXVHRI5HLQIRUFHPHQW/HDUQLQJ
5/
WRGHVLJQFRQWUROOHUVIRUVDIHW\FULWLFDOV\VWHPVLVDQ
LPSRUWDQWUHVHDUFKDUHD2QWKHRQHKDQG5/FDQIXQFWLRQLQDQGDGDSWWRFRPSOH[DQGFKDQJLQJ
HQYLURQPHQWVZLWKRXWUHTXLULQJDPRGHORIWKHV\VWHP2QWKHRWKHUKDQGLQVXFKV\VWHPVUREXVWQHVV
LVRIKLJKLPSRUWDQFHDVZHOODVZD\VWRJXDUDQWHHDQGFHUWLI\DOHYHORIUREXVWQHVV7KLVSURMHFW
LQYHVWLJDWHVVWDWHRIWKHDUWPHWKRGVIRUWUDLQLQJIRUDQGHYDOXDWLQJUREXVWQHVVLQDQHXUDOQHWZRUN
ZKHQDSSOLHGWR5/FRQWURORIDUHDOZRUOGV\VWHP7KHXVHRI3URMHFWHG*UDGLHQW'HVFHQW
3*'
DV
DQDGYHUVDU\IRUUREXVW'HHS5/DVZHOODVWKH/LSVFKLW]FRQVWDQWDVDPHDVXUHRIDQHXUDOQHWZRUN
FRQWUROOHU¶VUREXVWQHVVDUHHYDOXDWHG
7KHVWXG\LVFRQGXFWHGE\WUDLQLQJDQDJHQWWRSHUIRUPVZLQJXSDQGEDODQFLQJRID)XUXWD
SHQGXOXPDQGIXUWKHUWUDLQLQJLWZLWK3*'RIYDU\LQJPDJQLWXGHVDVDQDGYHUVDU\7KHDJHQWVDUH
HYDOXDWHGE\WKHLUUREXVWQHVVWRZDUGVQRUPDOO\GLVWULEXWHGPHDVXUHPHQWQRLVHDVZHOODVWKHLU
HVWLPDWHG/LSVFKLW]FRQVWDQW
7KHUHVXOWVVKRZWKDWZKLOHWUDLQLQJZLWK3*'GRHVUHVXOWLQEHWWHUUREXVWQHVVIRUDFODVVLILHURQWKH
01,67GDWDVHWDSSO\LQJWKHWHFKQLTXHWRWKH)XUXWDSHQGXOXPLQD'HHS5HLQIRUFHPHQW/HDUQLQJ
VHWWLQJLVQRWVRVLPSOH2QHRIDJHQWVPDQDJHGWRRXWSHUIRUPWKHEDVHOLQHDJHQWLQGLFDWLQJWKDW
ZKLOHWKHWHFKQLTXHPD\KDYHVRPHSURPLVHIXUWKHUILQHWXQLQJRIWKHWUDLQLQJSURFHVVLVQHFHVVDU\
)XUWKHUWKH/LSVFKLW]FRQVWDQWGLGQRWFRUUHODWHZLWKUREXVWQHVVSHUIRUPDQFHLQGLFDWLQJWKDWLWPD\
QRWEHDQLGHDOPHDVXUHRIDQHXUDOQHWZRUN¶VUREXVWQHVV
Keywords 

Classification system and/or index terms (if any) 

Supplementary bibliographical information 

ISSN and key title 

ISBN 

Language 
(QJOLVK
Number of pages 

Recipient’s notes 
Security classification 
KWWS
ZZZFRQWUROOWKVHSXEOLFDWLRQV

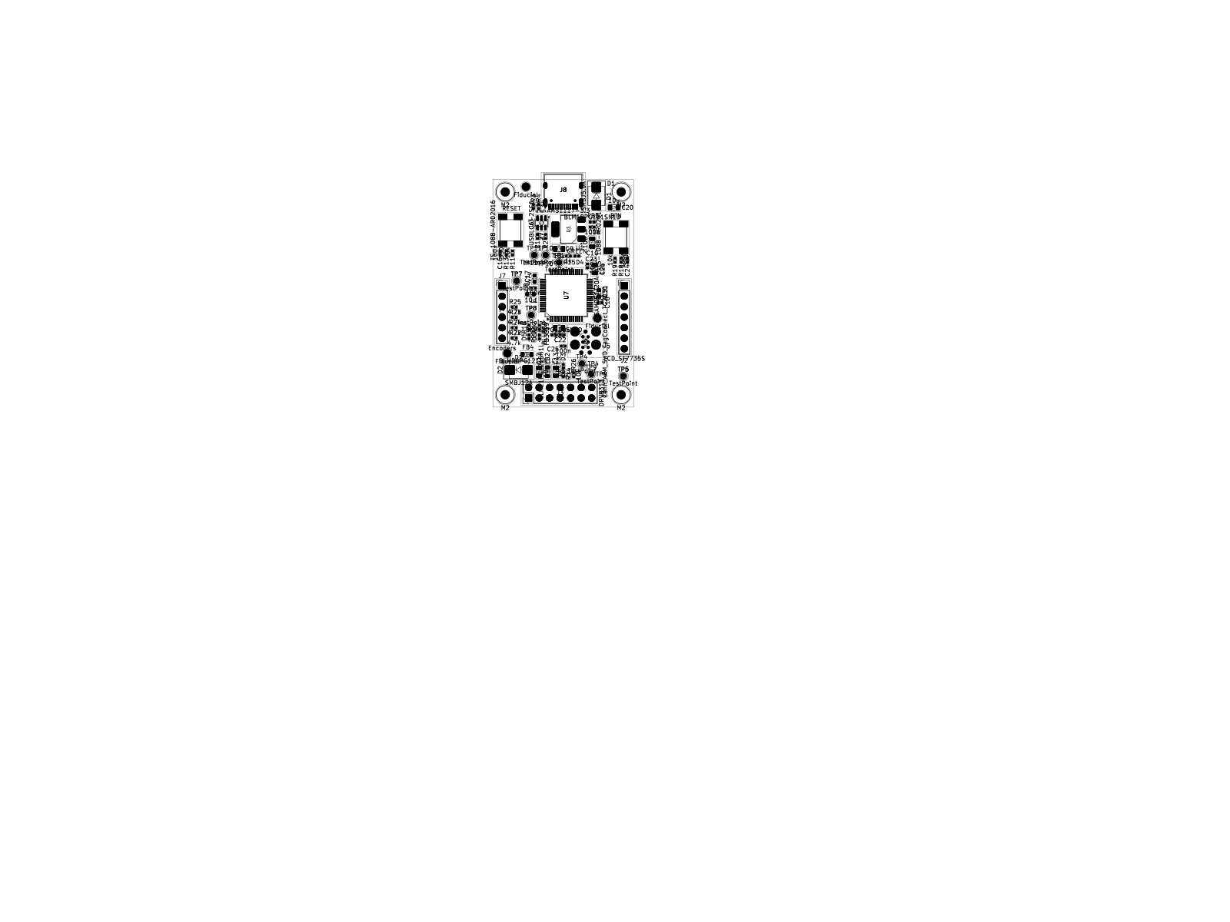
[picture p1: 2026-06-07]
hardware/pcb/furuta_pendulum_2d_view.png

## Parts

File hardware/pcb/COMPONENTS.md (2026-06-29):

# Hardware — Component Choices & PCB Design

This document explains the component selection rationale and PCB design decisions for the
Furuta pendulum controller. For the high-level system overview see the [root README](../../README.md).

---

## Component Choices

### MCU — ATSAMD51J20A

ARM Cortex-M4F, 120MHz, hardware FPU, 1MB flash, 192KB RAM.

| Requirement | Why this MCU |
|---|---|
| Neural network inference at 500–1000Hz | Hardware FPU handles float32 math natively — no soft-float penalty |
| FOC math (sin/cos, Clarke/Park transforms) | Same FPU advantage |
| Two separate I2C buses | Multiple SERCOMs configurable as I2C; rev1 uses SERCOM0 + SERCOM4 |
| USB debug output without extra chip | Integrated USB Full Speed (no UART-to-USB converter needed) |
| Enough flash for NN weights + code | 1MB — comfortably fits TFLM runtime + model weights + all drivers |
| Bare-metal friendly | Clean register map, excellent CMSIS headers, no mandatory framework |

The 64-pin QFN package gives enough I/O without going to a larger (harder to solder) package.

---

### Motor — GBM2804H-100T (Gimbal BLDC)

A brushless gimbal motor designed for camera stabilisation.

| Requirement | Why a gimbal motor |
|---|---|
| Smooth, low-cogging torque | Gimbal motors are wound with many poles specifically to minimise magnetic detents — cogging in a standard BLDC would introduce non-linearities that degrade NN performance |
| Low speed, high torque | Balancing a pendulum requires sustained torque at near-zero speed, not high RPM |
| Low inertia | Fast dynamic response is critical — the pendulum falls quickly |
| Predictable dynamics | The NN policy trained in simulation must transfer to real hardware; unpredictable motor behaviour widens the sim-to-real gap |

---

### Motor Driver — SimpleFOC Mini (DRV8313)

A compact 3-phase gate driver module.

| Requirement | Why FOC |
|---|---|
| Continuous torque at any speed | Field Oriented Control decouples torque from speed — you can command full torque at 0 RPM |
| High-level torque command interface | The NN outputs a normalised torque value (−1…+1); FOC translates this to phase currents |
| Compact form factor | SimpleFOC Mini fits on a small PCB, 2.5A continuous — matched to the GBM2804 |
| Complementary PWM | DRV8313 accepts three half-bridge inputs; TCC0 on the SAMD51 generates centre-aligned complementary PWM |

**DRV8313 control signals on PCB rev1:**

| Signal | Pin | Description |
|---|---|---|
| DRV_EN | PA11 | Active high — enables gate drive |
| DRV_FAULT (nFAULT) | PA12 | Active low, EIC interrupt — latches on overcurrent/overtemp |
| DRV_SLEEP (nSLEEP) | PA13 | Active low — puts driver into low-power sleep |
| DRV_RESET (nRESET) | PA14 | Active low pulse — clears fault latch |

**Startup sequence:** boot with DRV_EN low, DRV_SLEEP high → run encoder init → assert DRV_EN → monitor DRV_FAULT via EIC.

---

### Encoders — AS5600 (12-bit Magnetic, I2C)

Contactless magnetic rotary encoders. One on the motor shaft (arm), one on the pendulum pivot.

| Requirement | Why AS5600 |
|---|---|
| Absolute position | AS5600 gives absolute angle at power-on — no homing sequence needed |
| 12-bit resolution (4096 steps/rev) | ~0.088° per step — more than sufficient for control at 500Hz |
| Simple interface | I2C, single address (0x36), 3.3V compatible |
| Contactless | No wear, works through plastic covers |

**Address conflict:** Both AS5600s are fixed at I2C address 0x36. They are placed on
**separate I2C buses** (SERCOM0 for arm, SERCOM4 for pendulum) — this is hardwired into
PCB rev1 and cannot be changed in software.

**Double Furuta (PCB rev2):** A third AS5600 for the second pendulum will require a third
I2C bus on a spare SERCOM.

---

### Display — ST7735S 1.8" TFT LCD (128×160, SPI)

A small colour display for showing system state, encoder angles, and NN output during development and demo.

- SPI interface via SERCOM3 (PA22/PA23) — fast enough for real-time angle display
- Write-only (no MISO line needed) — saves a pin
- 3.3V logic compatible — direct MCU connection, no level shifter

---

## PCB Design — rev1

### Power Architecture

```
USB-C VBUS (5V) ──→ Pi-filter ──→ AMS1117-3.3 LDO ──→ 3.3V (logic)
                       |
                   SMBJ5.0A TVS

Motor connector (12V) ──→ SMBJ12A TVS ──→ Pi-filter ──→ 12VF (motor rail)
```

- **Logic (3.3V):** AMS1117-3.3 LDO from VBUS. Pi-filter on VBUS: 10µF → ferrite bead → 100nF
- **Motor rail (12V):** Enters on J3 pins 1–2, TVS clamps transients, pi-filter reduces switching noise, exits on J3 pins 3–4 to the DRV8313 module
- **PGND / GND isolation:** Motor ground (PGND) and logic ground (GND) are separate copper pours, joined at a single star point near the LDO via ferrite bead (BLM21PG121SN1L, 0805)

### Decoupling Strategy

- 100nF X7R 0402 bypass caps as close as possible to each MCU VDD pin
- 10µF X5R 0805 bulk caps on 3.3V and motor rails
- No Y5V or Z5U dielectrics (capacitance collapses under DC bias)

### Debug Interface

Tag-Connect TC2030 (with legs) footprint — no connector body on the PCB, the cable clips on during programming only.

| Signal | Notes |
|---|---|
| SWDIO / SWDCLK | PA30 / PA31 — standard ARM SWD |
| nRESET | 100nF cap to GND for noise immunity |
| SWO | PA27 — optional trace output |
| VTref | Connected to 3.3V rail |

Programmed via Atmel-ICE using SWD protocol (not JTAG).  
After the UF2 bootloader is flashed once via SWD, subsequent firmware updates can be done via USB (double-tap RESET → FEATHERBOOT drive appears).

### USB

- D+ / D− on PA24 / PA25 with 27Ω series resistors
- ESD protection diode on VBUS and data lines
- USB-C connector

### I2C Pull-ups

4.7kΩ pull-up resistors on SDA and SCL, one pair per bus, placed near the MCU rather than near the sensors.

---

## PCB Revision History

| Rev | Tag | Date | Notes |
|---|---|---|---|
| 1 | [`hw-rev1`](../../../releases/tag/hw-rev1) | 2026-06-07 | First production run — JLCPCB. Single Furuta (2 encoders, 2 I2C buses) |
| 2 | *(planned)* | TBD | Add AS5600 #3 on a third I2C bus (SERCOM) for double Furuta pendulum |

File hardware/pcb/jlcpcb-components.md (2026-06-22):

# JLCPCB Component Part Numbers

Reusable reference of LCSC part numbers. Blank LCSC = order manually.

## Resistors
| Value / Part | Package | LCSC Part # | Notes |
|---|---|---|---|
| 33Ω | 0402 | C25105 | USB D+/D− series termination |
| 330Ω | 0402 | C25104 | |
| 1k | 0402 | C11702 | |
| 2k | 0402 | C4109 | |
| 4.7k | 0402 | C25900 | I2C pull-ups |
| 5.1k | 0402 | C25905 | USB CC pull-downs |
| 10k | 0402 | C25744 | |

## Capacitors
| Value / Part | Package | LCSC Part # | Notes |
|---|---|---|---|
| 100n | 0402 | C1525 | X7R bypass |
| 4.7u | 0603 | C19666 | |
| 10u | 0805 | C440198 | X5R bulk |

## Ferrite Beads
| Value / Part | Package | LCSC Part # | Notes |
|---|---|---|---|
| BLM18PG121SN1D | 0603 | C14709 | 120Ω @ 100MHz, 500mA |
| BLM21PG121SN1L | 0805 | — | 120Ω @ 100MHz, 500mA, Order manually |
| GZ2012D601TF | 0805 | C1017 | 600Ω@100MHz, 500mA |
| GZ2012D101TF | 0805 | C1015 | 100Ω@100MHz, 800mA | 
| GZ1608D601TF | 0603 | C1002 | 600Ω@100MHz, 200mA

### Inductors
| Value / Part | Package | LCSC Part # | Notes |
|---|---|---|---|
| 10u | 0603 | C1035 | 30@2MHz, 3mA |

## Diodes / Protection

| Value / Part | Package | LCSC Part # | Notes |
|---|---|---|---|
| SMBJ5.0A | D_SMB | — | [mouser](https://www.mouser.dk/ProductDetail/78-SMBJ5.0A) |
| SMBJ12A | D_SMB | — | [mouser](https://www.mouser.dk/ProductDetail/78-SMBJ12A) |
| USBLC6-2SC6 | SOT-23-6 | — | USB ESD, order manually |

## LEDs

| Value / Part | Package | LCSC Part # | Notes |
|---|---|---|---|
| GREEN | 0805 | C2297 | |
| RED | 0603 | KT-0603R | |
| YELLOW | 0805 | KT-0805Y | |
| WHITE | 0603 | C2290 | |

## ICs

| Value / Part | Package | LCSC Part # | Notes |
|---|---|---|---|
| AMS1117-3.3 | SOT-223-3_TabPin2 | C6186 | 3.3V LDO |
| ATSAMD51J20A-A | TQFP-64_10x10mm_P0.5mm | — | [mouser](https://www.mouser.dk/ProductDetail/556-ATSAMD51J20AAU) |

## Switches / Connectors

| Value / Part | Package | LCSC Part # | Notes |
|---|---|---|---|
| TS-1088-AR02016 | SW_TS-1088-AR02016 | C720477 | Tactile switch |
| USB_C_Receptacle_USB2.0_14P | HRO_TYPE-C-31-M-12 | — | [mouser](https://www.mouser.dk/ProductDetail/179-UJ20CHGSMT1P16TR) |

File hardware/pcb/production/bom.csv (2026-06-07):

Comment | Designator | Footprint | LCSC Part Number
TS-1088-AR02016 | BTN1,RESET1 | SW_TS-1088-AR02016 | C720477
10u | C10,C12,C13,C19,C20,C21,C26,C9 | 0805 | C440198
100n | C15,C16,C18,C22,C23,C24,C25,C8 | 0402 | C1525
4.7u | C17 | 0603 | C19666
SMBJ5.0A | D1 | D_SMB
SMBJ12A | D2 | D_SMB
GREEN | D3,D4 | 0805 | C2297
RED | D5 | 0603 | KT-0603R
YELLOW | D6 | 0805 | KT-0805Y
GZ2012D601TF | FB2,FB5 | 0805 | C1017
BLM18PG121SN1D | FB3 | 0603 | C14709
GZ2012D101TF | FB4 | 0805 | C1015
LCD_ST7735S | J2 | PinHeader_1x07_P2.54mm_Vertical
DRV8313 | J3 | PinHeader_2x07_P2.54mm_Vertical
Encoders | J7 | PinHeader_1x06_P2.54mm_Vertical
USB_C_Receptacle_USB2.0_14P | J8 | USB_C_Receptacle_HRO_TYPE-C-31-M-12
10u | L1 | 0603 | C1035
33 | R1,R2 | 0402 | C25105
10k | R11,R19,R26 | 0402 | C25744
330 | R13,R18 | 0402 | C25104
2k | R14,R16 | 0402 | C4109
1k | R15,R17 | 0402 | C11702
4.7k | R22,R23,R24,R25 | 0402 | C25900
5.1k | R3,R4 | 0402 | C25905
TestPoint | TP1,TP10,TP11,TP4,TP5,TP7,TP8,TP9 | TestPoint_Pad_D1.5mm
AMS1117-3.3 | U1 | SOT-223-3_TabPin2 | C6186
USBLC6-2SC6 | U3 | SOT-23-6
ATSAMD51J20A-A | U7 | TQFP-64_10x10mm_P0.5mm

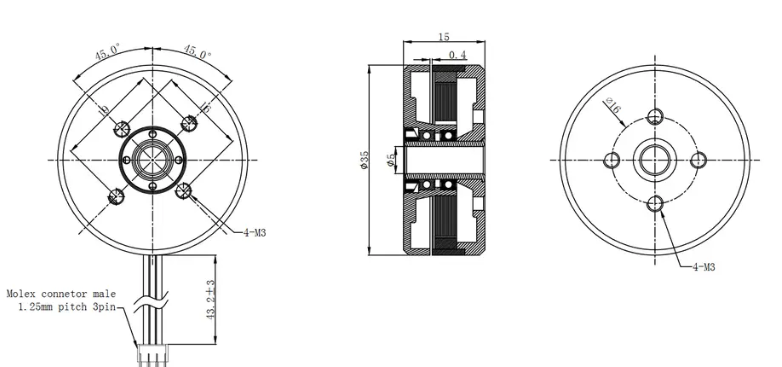
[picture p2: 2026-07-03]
hardware/components/GBM2804H-100T.png

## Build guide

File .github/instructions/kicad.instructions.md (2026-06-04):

---
description: "Use when designing, reviewing, or modifying the PCB schematic or layout in KiCad. Covers component choices, net naming, and layout guidelines for the Furuta pendulum PCB."
applyTo: "hardware/pcb/**"
---

# KiCad PCB Guidelines

## MCU — ATSAMD51J20A (TQFP-64)
- Decouple every VDD pin with 100nF X7R 0402 close to pin + bulk 10µF X5R 0805 per power domain
- SWD: Tag-Connect TC2030 (with legs) — `Conn_ARM_SWD_TagConnect_TC2030` footprint
  - Pin 1: VTref → 3.3V, Pin 2: SWDIO → PA31, Pin 3: nRESET → RESET, Pin 4: SWDCLK → PA30, Pin 5: GND, Pin 6: SWO → PA27
  - Add 100nF cap from nRESET to GND
- USB-C: 27Ω series on D+ and D-, ESD protection IC (USBLC6-2SC6)
- No external crystal — use internal DFLL48M locked to USB SOF

## Pin Assignment
| Pins | Function | Peripheral |
|---|---|---|
| PA00 / PA01 | I2C0_SDA / I2C0_SCL (arm encoder) | SERCOM0 |
| PA08 / PA09 / PA10 | PWM_A / PWM_B / PWM_C | TCC0 |
| PA11 | DRV_EN | GPIO out |
| PA12 | DRV_FAULT | GPIO in, interrupt |
| PA13 | DRV_SLEEP | GPIO out |
| PA14 | DRV_RESET | GPIO out |
| PA15 / PA16 | BTN1 / BTN2 | GPIO in, EIC |
| PA17 / PA18 | LED1 / LED2 | GPIO out |
| PA19 | LCD_RST | GPIO out |
| PA20 | LCD_CS | GPIO out |
| PA21 | LCD_DC | GPIO out |
| PA22 / PA23 | LCD_MOSI / LCD_SCK | SERCOM3 SPI |
| PA24 / PA25 | USB_DM / USB_DP | USB |
| PA30 / PA31 | SWDIO / SWDCLK | SWD |
| PB08 / PB09 | I2C1_SDA / I2C1_SCL (pendulum encoder) | SERCOM4 |

## Net Naming
- Net names are generally left as KiCad assigns them — do not rename nets just to match a convention
- One explicit exception: the motor-side ground plane is named **`PGND`** (not auto-generated)
- The logic-side ground is `GND` (KiCad default)
- Power rails use whatever name KiCad assigns from the placed power symbol (e.g. `+3.3V`, `+5V`, `+12V`)

## Power Architecture
- **Logic**: USB-C VBUS (5V) → AMS1117-3.3 LDO → 3.3V
- **Motor**: J1 VM connector (12V) → SMBJ12A TVS → pi-filter → +VM → DRV8313
- TVS diodes: SMBJ12A on +12V/+VM (shunt to PGND), SMBJ5.0A on +5V VBUS (shunt to GND)
- TVS package: both use SMB (DO-214AA) — footprint `Diode_SMD:D_SMB`
- Pi-filter on VBUS: C1 10µF (VBUS side) → ferrite bead (~600Ω @ 100MHz) → C2 100nF (5V rail side)
- PGND and GND joined via ferrite bead (FB4, BLM21PG121SN1L, 0805) at star point near LDO
- FB3 (BLM18PG121SN1D, 0603) on MCU VSW pin for internal switching regulator filter

## Capacitor Types
- 100nF bypass: X7R 0402 MLCC
- 10µF bulk: X5R 0805 MLCC
- Do NOT use Y5V or Z5U — poor stability over temperature and voltage

## Layout Priorities
1. Decouple caps as close to MCU VDD pins as possible
2. Keep motor phase traces short and wide (high current, 1A+ per phase)
3. PGND and GND are separate pours — connect only at star point near LDO/power input
4. Keep USB D+/D- as matched-length differential pair
5. Place TVS diodes as close as possible to their respective input connectors
6. I2C pull-up resistors (4.7kΩ) placed on PCB near MCU, one pair per bus
7. DRV8313 and encoder signals grouped near their respective connectors

## Connectors
- Motor phases: 3-pin Molex Micro-Fit (43045-0300), locking — use shielded cable, shield to PGND at PCB end only
- AS5600 encoders: 4-pin headers for I2C + 3.3V + GND
- VM input (J1): 2-pin 2.54mm pin header for 12V PSU
- SWD: Tag-Connect TC2030 (with legs) — no connector body, pads + holes only
- USB: USB-C receptacle
- LCD (J2): 7-pin 2.54mm header (VCC, GND, SCK, MOSI, CS, DC, RST)
- Buttons: 10kΩ pull-up to 3.3V on PCB; SW3 connected to PB00 via direct wire (no net label)
- LEDs: 4 total — 2 power indicators (3.3V and 12V rails), 2 user GPIO (PA17/PA18)

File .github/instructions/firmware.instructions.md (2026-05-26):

---
description: "Use when writing, reviewing, or debugging firmware code for the ATSAMD51J20A. Covers bare-metal C conventions, register access, peripheral setup, and CMSIS-NN inference."
applyTo: "firmware/**"
---

# Firmware Guidelines

## Style
- Pure C (C11) — no C++ unless absolutely necessary
- No HAL, no ASF, no Arduino — direct register access via CMSIS headers only
- All peripheral configuration done via register writes, never via library calls
- Prefer `volatile` for all hardware register accesses

## Naming
- Peripherals: `SERCOM0`, `TC0`, `TCC0` etc. — use exact CMSIS names
- Functions: `snake_case`, prefixed by module — e.g. `i2c_init()`, `encoder_read_angle()`
- Constants: `ALL_CAPS` with module prefix — e.g. `AS5600_ADDR`, `PWM_FREQ_HZ`

## Pin Assignment
| Pins | Function | Peripheral |
|---|---|---|
| PA00 / PA01 | I2C0_SDA / I2C0_SCL (arm encoder) | SERCOM0 |
| PA08 / PA09 / PA10 | PWM_A / PWM_B / PWM_C | TCC0 WO[0/1/2] |
| PA11 | DRV_EN (active high) | GPIO out |
| PA12 | DRV_FAULT (~nFT, active low) | GPIO in, EIC interrupt |
| PA13 | DRV_SLEEP (~nSP, active low) | GPIO out |
| PA14 | DRV_RESET (~nRT, active low) | GPIO out |
| PA15 / PA16 | BTN1 / BTN2 | GPIO in, EIC interrupt |
| PA17 / PA18 | LED1 / LED2 | GPIO out |
| PA19 | LCD_RST | GPIO out |
| PA20 | LCD_CS | GPIO out |
| PA21 | LCD_DC | GPIO out |
| PA22 / PA23 | LCD_MOSI / LCD_SCK | SERCOM3 SPI |
| PA24 / PA25 | USB_DM / USB_DP | USB |
| PA30 / PA31 | SWDIO / SWDCLK | SWD |
| PB00 | BTN3 | GPIO in, EIC interrupt |
| PB08 / PB09 | I2C1_SDA / I2C1_SCL (pendulum encoder) | SERCOM4 |

## Peripherals
- **I2C0** (AS5600 arm encoder): SERCOM0, PA00/PA01, address 0x36
- **I2C1** (AS5600 pendulum encoder): SERCOM4, PB08/PB09, address 0x36
- **SPI** (ST7735S LCD): SERCOM3, PA22/PA23, write-only (no MISO)
- **TCC0** (3-phase PWM for DRV8313): center-aligned, 3 complementary outputs on PA08–PA10
- **USB**: CDC class for debug output — no printf to UART
- **EIC**: PA12 (DRV_FAULT falling edge), PA15/PA16/PB00 (button press)
- **Clock**: Internal DFLL48M locked to USB SOF — no external crystal

## DRV8313 Control Sequence
1. Boot with DRV_EN low, DRV_SLEEP high (driver disabled, not sleeping)
2. Run encoder init and self-checks
3. Assert DRV_EN high to enable driver only when ready
4. Monitor DRV_FAULT via EIC interrupt — on fault: disable DRV_EN immediately, log fault, attempt reset via DRV_RESET pulse

## Neural Network
- Inference via CMSIS-NN — use `arm_fully_connected_f32` and related functions
- Weights stored in flash as `const float` arrays
- Control loop target: 500–1000Hz
- Inputs: θ_arm, θ_pendulum, ω_arm, ω_pendulum (all in radians / radians per second)
- Output: torque command (normalized -1.0 to 1.0)

## Build
- CMake — `cmake -B build && cmake --build build`
- Toolchain: `arm-none-eabi-gcc`
- Debug: Atmel-ICE + OpenOCD via SWD header (J6)

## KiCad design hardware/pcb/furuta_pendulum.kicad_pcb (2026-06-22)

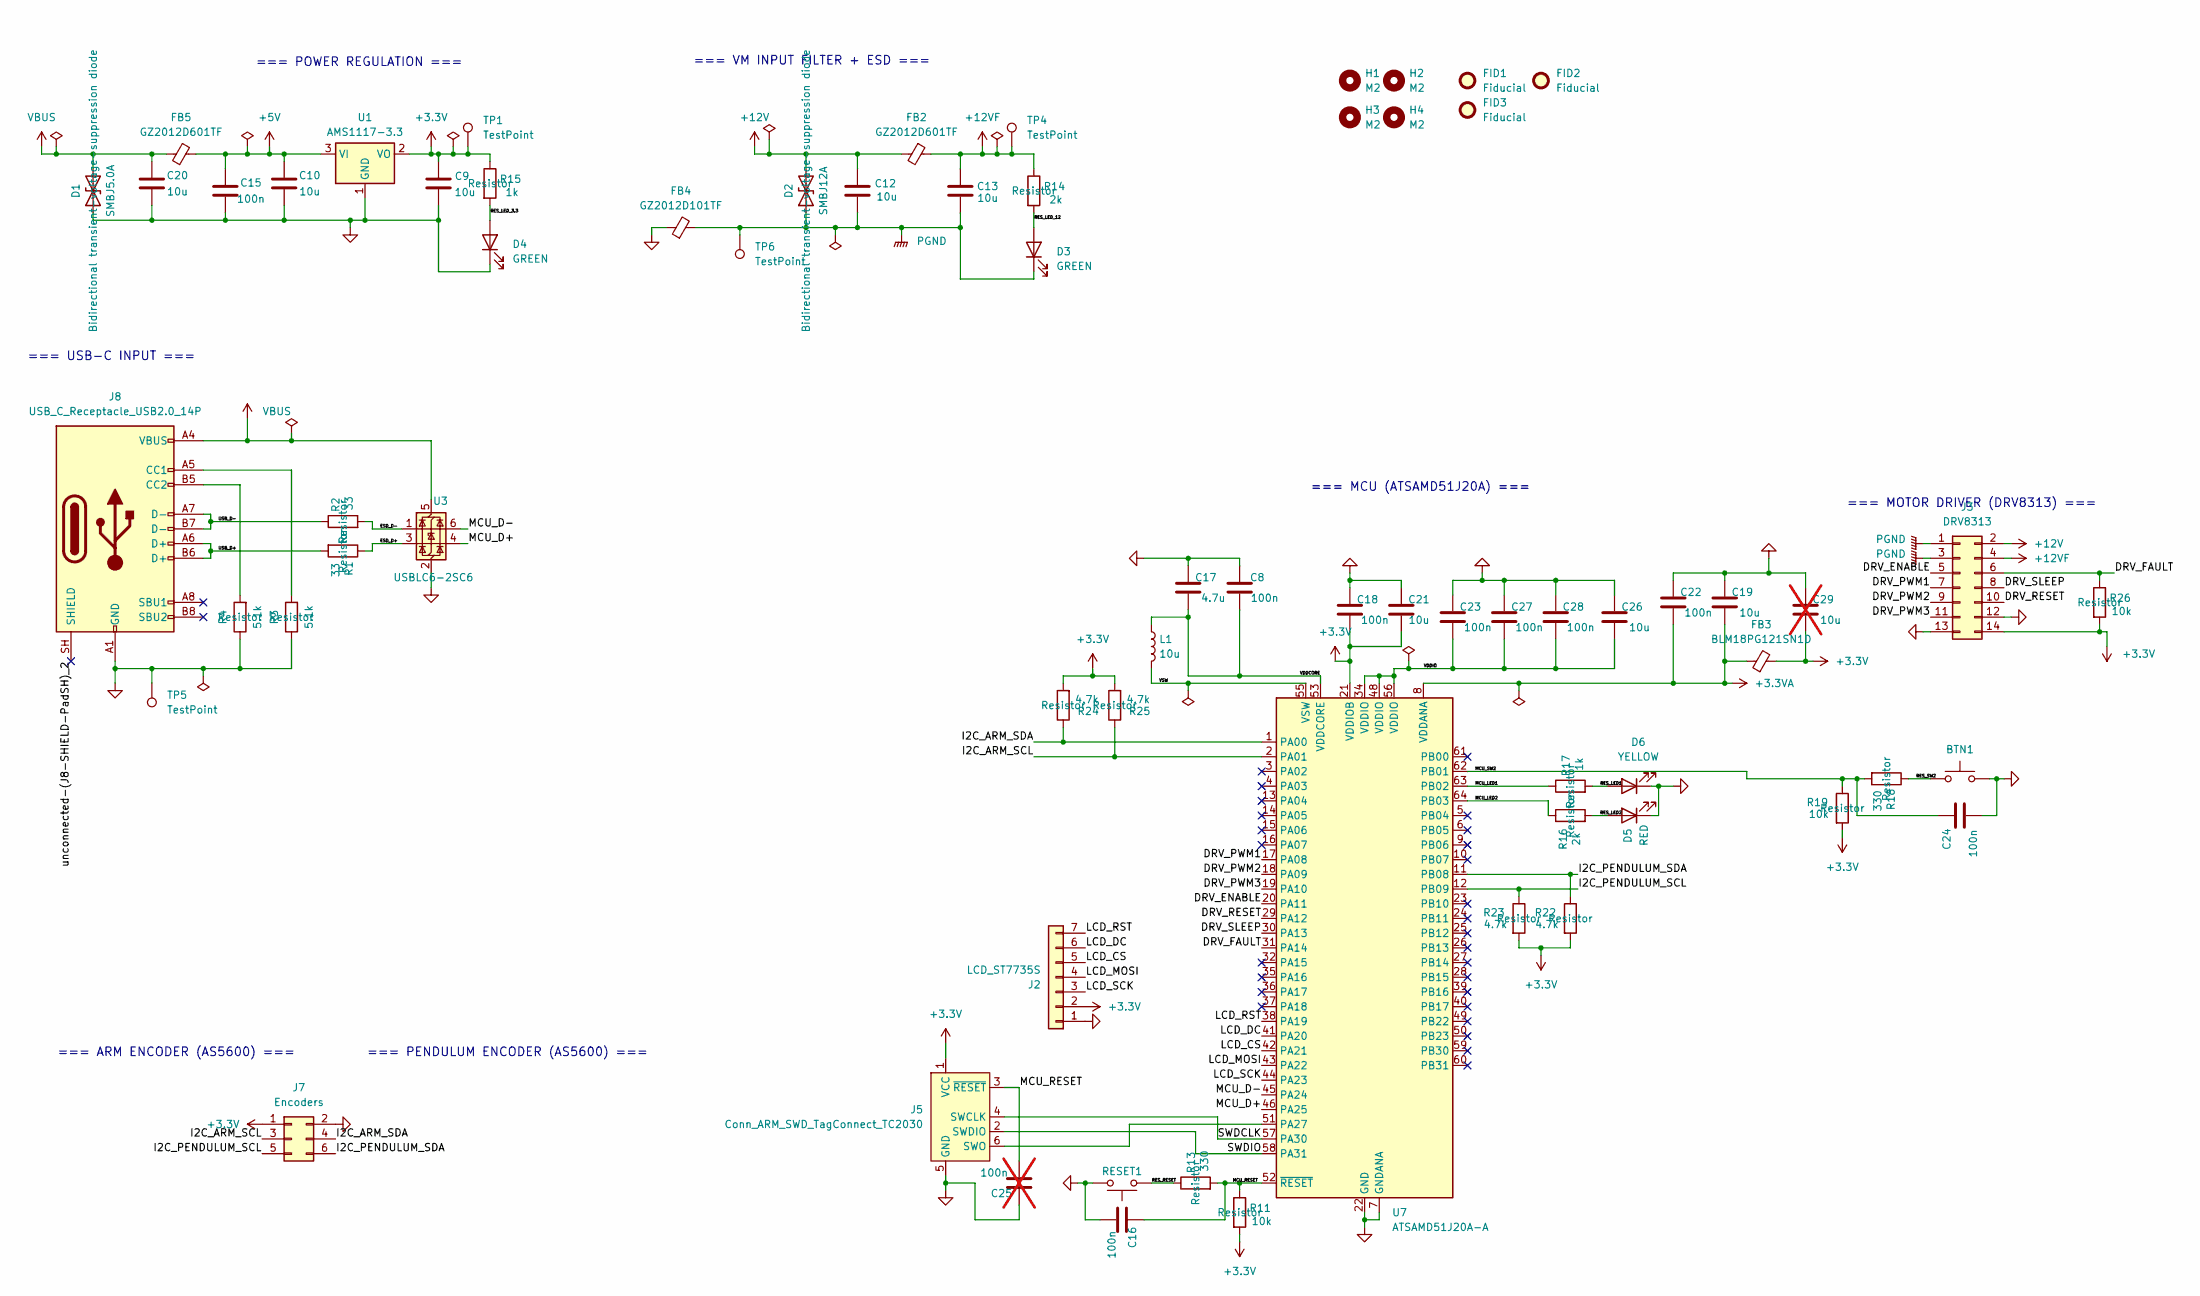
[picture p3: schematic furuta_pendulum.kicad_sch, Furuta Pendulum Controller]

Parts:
BTN1: TS-1088-AR02016; SW_TS-1088-AR02016; LCSC Part # C720477
C8, C15, C16, C18, C22, C23, C24, C27, C28: 100n; C_0402_1005Metric; LCSC Part # C1525
C9, C10, C12, C13, C19, C20, C21, C26: 10u; C_0805_2012Metric; LCSC Part # C440198
C17: 4.7u; C_0603_1608Metric; LCSC Part # C19666
C25: 100n; C_0402_1005Metric; LCSC Part # C1525; not fitted
C29: 10u; C_0805_2012Metric; LCSC Part # C440198; not fitted
D1: SMBJ5.0A; D_SMB
D2: SMBJ12A; D_SMB
D3, D4: GREEN; LED_0805_2012Metric; LCSC Part # C2297
D5: RED; LED_0603_1608Metric; LCSC Part # KT-0603R
D6: YELLOW; LED_0805_2012Metric; LCSC Part # KT-0805Y
FB2, FB5: GZ2012D601TF; L_0805_2012Metric; LCSC Part # C1017
FB3: BLM18PG121SN1D; L_0603_1608Metric; LCSC Part # C14709
FB4: GZ2012D101TF; L_0805_2012Metric; LCSC Part # C1015
FID1, FID2, FID3: Fiducial; Fiducial_1mm_Mask2mm
H1, H2, H3, H4: M2; MountingHole_2.2mm_M2
J2: LCD_ST7735S; PinHeader_1x07_P2.54mm_Vertical
J3: DRV8313; PinHeader_2x07_P2.54mm_Vertical
J5: Conn_ARM_SWD_TagConnect_TC2030; Tag-Connect_TC2030-IDC-FP_2x03_P1.27mm_Vertical
J7: Encoders; PinHeader_1x06_P2.54mm_Vertical
J8: USB_C_Receptacle_USB2.0_14P; USB_C_Receptacle_HRO_TYPE-C-31-M-12
L1: 10u; L_0603_1608Metric; LCSC Part # C1035
R1, R2: 33; R_0402_1005Metric; LCSC Part # C25105
R3, R4: 5.1k; R_0402_1005Metric; LCSC Part # C25905
R11, R19, R26: 10k; R_0402_1005Metric; LCSC Part # C25744
R13, R18: 330; R_0402_1005Metric; LCSC Part # C25104
R14, R16: 2k; R_0402_1005Metric; LCSC Part # C4109
R15, R17: 1k; R_0402_1005Metric; LCSC Part # C11702
R22, R23, R24, R25: 4.7k; R_0402_1005Metric; LCSC Part # C25900
RESET1: TS-1088-AR02016; SW_TS-1088-AR02016; LCSC Part # C720477
TP1, TP4, TP5, TP6: TestPoint; TestPoint_Pad_D1.5mm
U1: AMS1117-3.3; SOT-223-3_TabPin2; LCSC Part # C6186
U3: USBLC6-2SC6; SOT-23-6
U7: ATSAMD51J20A-A; TQFP-64_10x10mm_P0.5mm

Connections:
+3.3V: C9.1, C18.2, C21.2, C29.2, FB3.2, J2.2, J3.14, J5.1 (VCC), J7.1, R11.2, R15.1, R19.2, R22.2, R23.2, R24.2, R25.2, R26.2, TP1.1 (1_1), U1.2 (VO), U7.21 (VDDIOB)
+3.3VA: C19.2, C22.2, FB3.1, U7.8 (VDDANA)
+5V: C10.1, C15.1, FB5.2, U1.3 (VI)
+12V: C12.1, D2.2 (A2), FB2.2, J3.2
+12VF: C13.1, FB2.1, J3.4, R14.1, TP4.1 (1_1)
/DRV_ENABLE: J3.5, U7.20 (PA11)
/DRV_FAULT: J3.6, R26.1, U7.31 (PA14)
/DRV_PWM1: J3.7, U7.17 (PA08)
/DRV_PWM2: J3.9, U7.18 (PA09)
/DRV_PWM3: J3.11, U7.19 (PA10)
/DRV_RESET: J3.10, U7.29 (PA12)
/DRV_SLEEP: J3.8, U7.30 (PA13)
/ESD_D+: R1.1, U3.3 (I/O2)
/ESD_D-: R2.2, U3.1 (I/O1)
/I2C_ARM_SCL: J7.3, R25.1, U7.2 (PA01)
/I2C_ARM_SDA: J7.4, R24.1, U7.1 (PA00)
/I2C_PENDULUM_SCL: J7.5, R23.1, U7.12 (PB09)
/I2C_PENDULUM_SDA: J7.6, R22.1, U7.11 (PB08)
/LCD_CS: J2.5, U7.42 (PA21)
/LCD_DC: J2.6, U7.41 (PA20)
/LCD_MOSI: J2.4, U7.43 (PA22)
/LCD_RST: J2.7, U7.38 (PA19)
/LCD_SCK: J2.3, U7.44 (PA23)
/MCU_D+: U3.4 (I/O2), U7.46 (PA25)
/MCU_D-: U3.6 (I/O1), U7.45 (PA24)
/MCU_LED1: R17.1, U7.63 (PB02)
/MCU_LED2: R16.1, U7.64 (PB03)
/MCU_RESET: C16.1, C25.2, J5.3 (~RESET), R11.1, R13.2, U7.52 (~RESET)
/MCU_SW2: C24.1, R18.2, R19.1, U7.62 (PB01)
/RES_LED1: D6.2 (A), R17.2
/RES_LED2: D5.2 (A), R16.2
/RES_LED_3.3: D4.2 (A), R15.2
/RES_LED_12: D3.2 (A), R14.2
/RES_RESET: R13.1, RESET1.1 (A), RESET1.2 (A)
/RES_SW2: BTN1.1 (A), BTN1.2 (A), R18.1
/SWDCLK: J5.4 (SWCLK), U7.57 (PA30)
/SWDIO: J5.2 (SWDIO), U7.58 (PA31)
/USB_D+: J8.A6 (D+), J8.B6 (D+), R1.2
/USB_D-: J8.A7 (D-), J8.B7 (D-), R2.1
/VDDCORE: C8.2, C17.2, L1.1, U7.53 (VDDCORE)
/VDDIO: C23.2, C26.2, C27.2, C28.2, U7.34 (VDDIO), U7.48 (VDDIO), U7.56 (VDDIO)
/VSW: L1.2, U7.55 (VSW)
/unconnected-(J8-SHIELD-PadSH)_2: J8.SH (SHIELD)
/unconnected-(J8-SHIELD-PadSH)_2_1: J8.SH (SHIELD)
/unconnected-(J8-SHIELD-PadSH)_2_2: J8.SH (SHIELD)
/unconnected-(J8-SHIELD-PadSH)_2_3: J8.SH (SHIELD)
GND: BTN1.3 (B), BTN1.4 (B), C8.1, C9.2, C10.2, C15.2, C16.2, C17.1, C18.1, C19.1, C20.2, C21.1, C22.1, C23.1, C24.2, C25.1, C26.1, C27.1, C28.1, C29.1, D1.1 (A1), D4.1 (K), D5.1 (K), D6.1 (K), FB4.1, J2.1, J3.12, J3.13, J5.5 (GND), J7.2, J8.A1 (GND), J8.A12 (GND), J8.B1 (GND), J8.B12 (GND), R3.1, R4.1, RESET1.3 (B), RESET1.4 (B), TP5.1 (1_1), U1.1 (GND), U3.2 (GND), U7.7 (GNDANA), U7.22 (GND), U7.33 (GND), U7.47 (GND), U7.54 (GND)
unnamed: J5.6 (SWO), U7.51 (PA27)
unnamed: J8.A5 (CC1), R3.2
unnamed: J8.B5 (CC2), R4.2
PGND: C12.2, C13.2, D2.1 (A1), D3.1 (K), FB4.2, J3.1, J3.3, TP6.1 (1_1)
VBUS: C20.1, D1.2 (A2), FB5.1, J8.A4 (VBUS), J8.A9 (VBUS), J8.B4 (VBUS), J8.B9 (VBUS), U3.5 (VBUS)

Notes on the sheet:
=== POWER REGULATION ===
=== USB-C INPUT ===
=== MCU (ATSAMD51J20A) ===
=== MOTOR DRIVER (DRV8313) ===
=== ARM ENCODER (AS5600) ===
=== PENDULUM ENCODER (AS5600) ===
=== VM INPUT FILTER + ESD ===

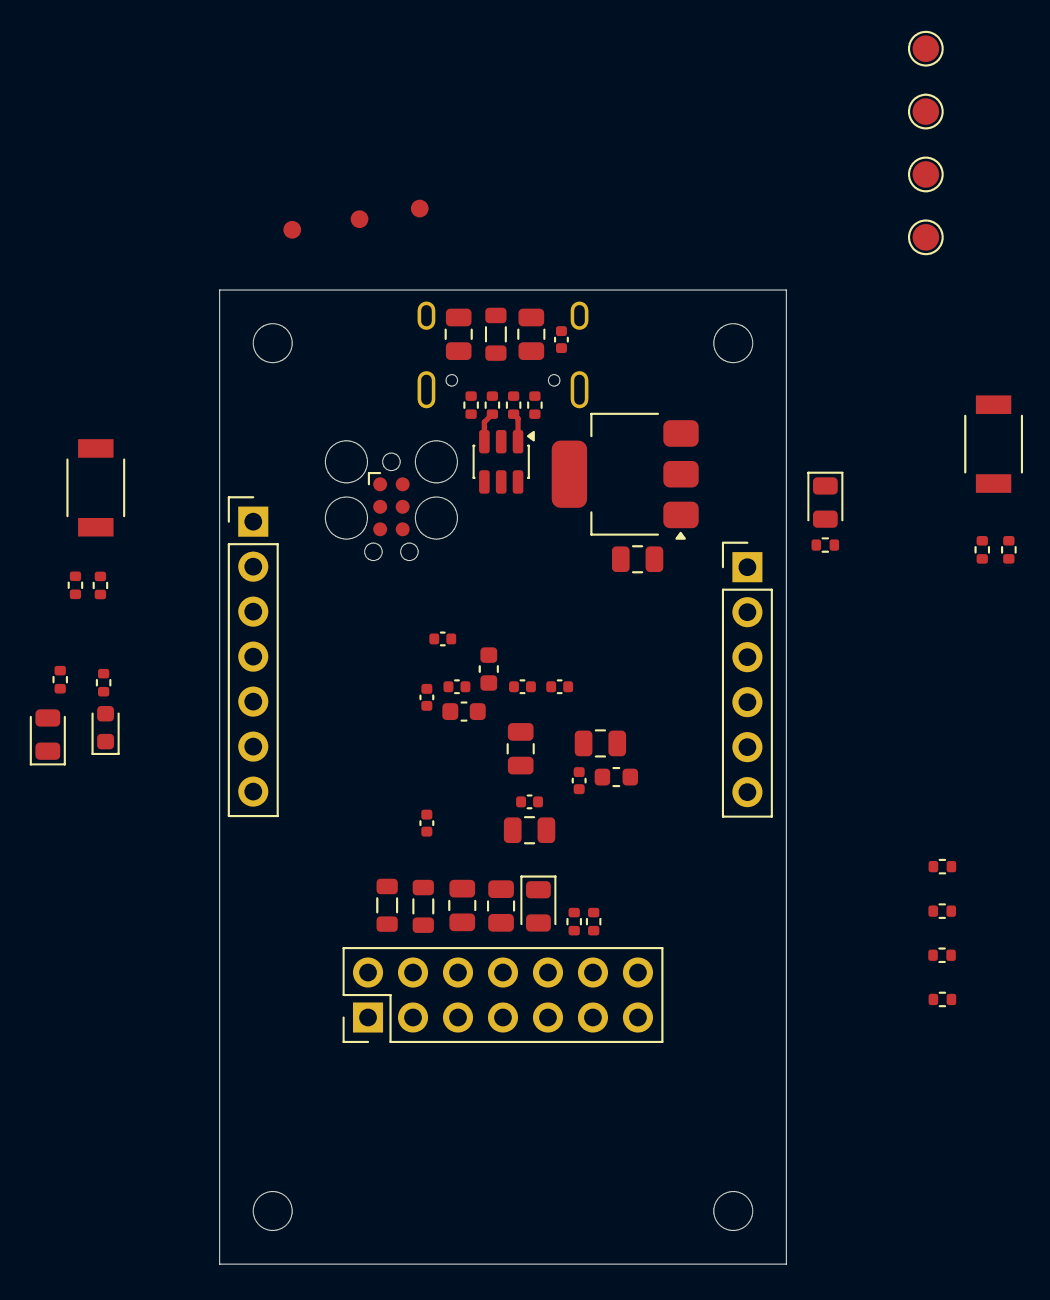
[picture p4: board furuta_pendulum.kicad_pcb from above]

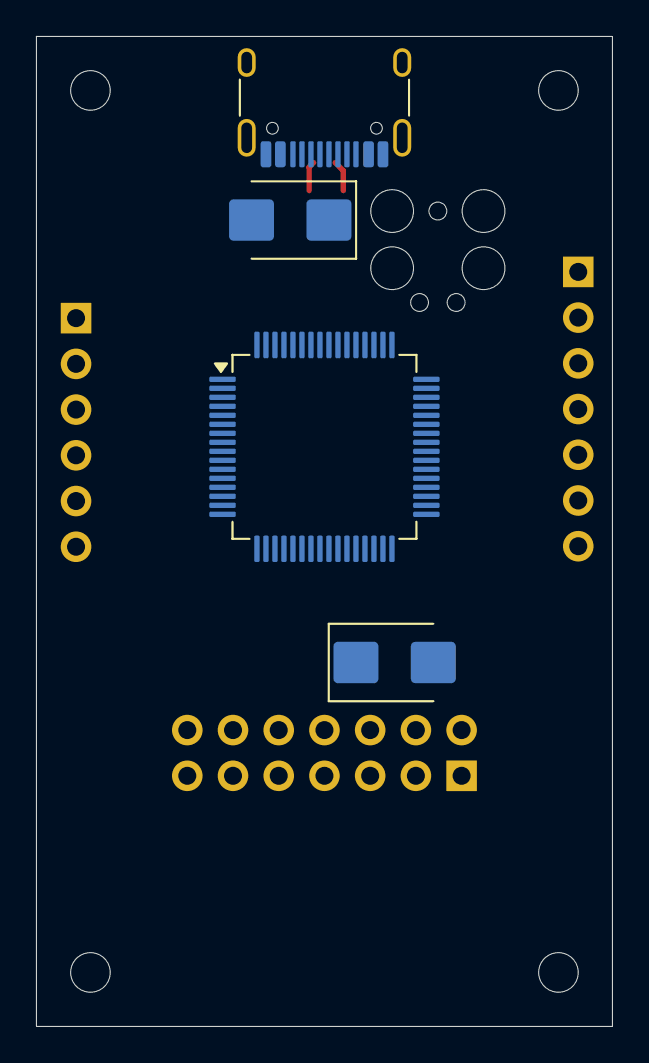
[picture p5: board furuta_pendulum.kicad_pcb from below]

Board: 4 copper layers, 32.0 x 55.0 mm, 67 parts (4 on the bottom side), 48 nets.

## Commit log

2026-05-24 Add .github customizations, agents, instructions and KiCad MCP config
2026-05-26 PCB schematic, footprints, net classes and documentation updates
    - Add furuta_pendulum.kicad_sch: complete schematic with all footprints assigned
    - Add furuta_pendulum.kicad_pro: net class assignments (Power_LV, Power_HV, USB_Diff)
    - Add furuta_pendulum.kicad_pcb: initial PCB layout file
    - Add fp-lib-table: register furuta_pendulum custom footprint library
    - Add SW_TS-1088-AR02016.kicad_mod: custom footprint for JLCPCB basic tactile switch (pads 1-4)
    - Add SAM D5 families datasheet to docs/
    - Update README: fix MCU package (QFN->TQFP), power section, pin table (add PB00/BTN3), open to-dos
    - Update kicad.instructions.md: fix package, net naming policy, power arch, connectors
    - Update firmware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
    [furuta_pendulum.kicad_pcb, furuta_pendulum.kicad_sch]
2026-05-26 Add PCB layout file and project local settings
    [furuta_pendulum.kicad_pcb]
2026-05-26 Add .gitignore for KiCad, build artifacts and OS files
2026-06-04 Update PCB docs: TVS diodes, pi-filter, Tag-Connect SWD, SWO
    [furuta_pendulum.kicad_sch]
2026-06-07 PCB Rev 1 — production release to JLCPCB
    Includes final schematic and layout changes, production files (Gerbers,
    BOM, positions), JLCPCB component mapping, Claude Code project instructions
    and MCP config, and component datasheet.
    [bom.csv, designators.csv, furuta_pendulum.kicad_pcb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]
2026-06-07 Add PCB revision history table to README
    Documents Rev 1 production release sent to JLCPCB (tagged hw-rev1).
2026-07-10 Add RL training pipeline for neural network controllers
    - Physics simulation: Lagrangian EOM with RK4 integrator (envs/physics.py)
    - Gymnasium environment: two modes (balance/swingup), cosine reward,
    domain randomisation, realistic handoff reset velocities (envs/furuta_env.py)
    - PPO training script with ep_info_buffer-based curriculum (train.py)
    - requirements.txt: pinned-range deps for Python 3.11
    Balance reward changed from quadratic -(theta^2) to cosine cos(theta_err)
    for smooth gradient signal across all angles. Balance resets within +/-30 deg
    of upright with bounded velocities (w1<=3, w2<=1.5 rad/s) to match
    realistic swing-up handoff conditions.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
2026-07-11 Fix RL training: reward scale, difficulty reset, physics params
    - furuta_env.py: fix arm-velocity penalty to use normalised+clipped w1
    so it stays in [0, 0.1] and can never exceed the cosine angle reward.
    Previously 0.01*w1^2 with raw rad/s caused penalty > 1.0 at OMEGA1_MAX,
    blocking all learning (reward flat at -1300 across 500k steps).
    - furuta_env.py: fix reset() to respect self.difficulty instead of
    hardcoding max_angle=30deg. Curriculum setter had no effect before.
    - furuta_env.py: scale initial velocities with difficulty so easy stages
    (near-vertical) start with near-zero arm/pendulum velocity.
    - physics.py: update placeholder params to physically reasonable values
    for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
2026-07-11 Add 3D real-time visualizer for balance controller
    visualize.py: animates the balance policy in 3D using matplotlib.
    Shows arm (blue), pendulum (red), upright reference (green dashed),
    floor shadows, live telemetry overlay and a normalised torque bar.
    Usage:
    python visualize.py # seed 1, ~30 deg start
    python visualize.py --seed 8 # hardest start (~45 deg)
2026-07-11 Add --learning-rate, --ent-coef, --arm-penalty CLI args to train.py
    - train() now accepts learning_rate, ent_coef, arm_penalty_coeff params
    - make_env() passes arm_penalty_coeff to env._arm_penalty_coeff
    - furuta_env._reward reads _arm_penalty_coeff via getattr (default 0.175)
    so train.py and tune.py both set it the same way — no monkey-patching
    - tune.py: removed the _patched_reward monkey-patch (now redundant)
    - tune.py: also committed for the first time (was previously uncommitted)
    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
2026-07-11 Switch arm penalty from quadratic to linear
    Quadratic (w1_norm^2) was too forgiving at moderate speeds — at 40%
    arm speed the penalty was only 0.028, making lazy circles essentially
    free. Linear (|w1_norm|) is 2.5x stronger at that speed (0.070) while
    keeping the same max penalty at full speed (0.175).
2026-07-11 Revert arm penalty to quadratic
    Linear penalty was too aggressive at low speeds, disrupting the
    balance reward signal — model stuck below 0 after 2M steps.
    Back to quadratic (w1_norm^2) which worked well at the ~1800 peak.
2026-07-11 Add --load-model arg to train.py for two-phase training
    Enables loading a saved checkpoint and continuing with different
    reward parameters (e.g. higher arm penalty) without retraining
    from scratch. The loaded model keeps all weights; learning_rate
    and ent_coef are updated from CLI args.
    Workflow:
    Phase 1 - train balancing from scratch, low arm penalty:
    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
2026-07-11 Add --linear-penalty flag for phase 2 fine-tuning
    Phase 1 (from scratch): quadratic penalty — forgiving at low speeds
    so the agent can spin freely while learning to balance.
    Phase 2 (load trained model): linear penalty — 2.5x stronger at
    moderate speeds, directly targeting lazy circles without hurting
    the already-learned balance policy.
    Example workflow:
    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
2026-07-11 Add training summary printed at end of each run
    Reads logs/{mode}_eval/evaluations.npz after training and prints:
    - Best eval reward and the step it was reached
    - Final reward (mean of last 3 evals) +/- std
    - Trend (reward change per 100k steps over last 20% of run)
    Detects and explains four convergence issues:
    - Still rising -> run longer
    - Late collapse -> lower ent_coef or arm_penalty
    - Low plateau -> reward shaping problem
    - High variance -> lower learning rate
    verbose=0 is kept on the model (noisy per-update output); the
    summary gives all the useful information in one clean block.
2026-07-11 Fix reward: remove ARM_OMEGA_PENALTY_SCALE, restore OMEGA1_MAX normalisation
    ARM_OMEGA_PENALTY_SCALE=2.0 was introduced by an editor edit and caused
    the penalty to saturate at full coeff from just 2 rad/s onward. With
    coeff=0.2 this meant the agent paid 0.20/step for any moderate arm
    movement during early training, overwhelming the balance reward and
    preventing learning entirely (stuck at ~0 for 2M steps).
    Back to OMEGA1_MAX (4*pi ~= 12.6 rad/s) which was the working baseline.
    At 2 rad/s the penalty is now 0.005 instead of 0.200.
2026-07-11 Fix arm penalty comment clarity; add dynamic model listing to --help
    - Remove misleading ARM_OMEGA_PENALTY_SCALE references left over from a
    failed fix attempt; clarify that OMEGA1_MAX normalises both observations
    and the penalty (consistent signal, increase coeff to strengthen)
    - _available_models() in train.py now scans models/ at --help time,
    listing top-level zips individually and summarising checkpoint
    subdirectories as a count so the help output stays readable
2026-07-11 Rework balance reward and reset to fix spinning arm
    Reward:
    - Gate arm penalty by max(0, cos(theta_err)): arm moves freely during
    recovery, penalty only active when pendulum is near upright.
    Prevents the 'stutter' failure (uniform penalty caused brief torque
    bursts) and the 'spinning cheat' (spinning helped balance).
    - Raise default coeff to 2.0: at 200deg/s steady spin the episode cost
    is ~309 units, well above the training noise floor (~150 std), making
    the gradient signal clearly visible. coeff=0.5 only cost ~77 units.
    Reset:
    - Arm velocity (w1) now sampled from full +-OMEGA1_MAX range independent
    of difficulty. Previously capped at 3.0 * difficulty = 40deg/s at
    difficulty=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
2026-07-11 Fix: cap initial arm velocity at OMEGA1_MAX/2 to ensure positive reward
    With coeff=2.0 and initial arm sampled from full +-OMEGA1_MAX (720 deg/s),
    29% of episode starts gave NEGATIVE reward even at perfect pendulum balance
    (arm above 509 deg/s). The agent could never discover what good looks like.
    Cap initial arm velocity at OMEGA1_MAX/2 (360 deg/s = 1 rev/s):
    - Reward floor at perfect balance: +0.5 (always positive)
    - 200 deg/s steady spin still costs 309 units/episode (above noise floor)
    - Covers realistic swing-up handoff arm speeds
    General rule: penalty_coeff * (w1_max/scale)^2 must be < 1.0, otherwise
    the reward is negative at the optimum and PPO cannot learn.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
2026-07-15 Fix missing arm-pendulum coupling in physics; rework balance curriculum
    physics.py:
    - The equations of motion solved alpha1 and alpha2 independently, missing
    the cross-inertia term (M12 = m2*L1*Lp*cos(theta2)) that couples them.
    This meant torque had ZERO instantaneous effect on the pendulum whenever
    the arm was at rest (alpha2 only responded to a w1^2 centrifugal term),
    and the system lost ~8.7% of total mechanical energy over 3s with zero
    friction and zero torque -- a physically impossible result that proved
    the equations were wrong, not just simplified. Every prior training
    attempt's "arm must keep spinning to balance" behavior was a correct RL
    solution to this broken mode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
